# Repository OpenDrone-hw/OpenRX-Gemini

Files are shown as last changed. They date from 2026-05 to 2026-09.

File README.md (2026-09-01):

# OpenRX Gemini

Open-source dual-radio, dual-band ExpressLRS receiver for FPV aircraft. OpenRX
Gemini combines an ESP32-C3 with two LR1121 radio chains and two U.FL antenna
interfaces for Gemini and Xrossband operation.

<p>
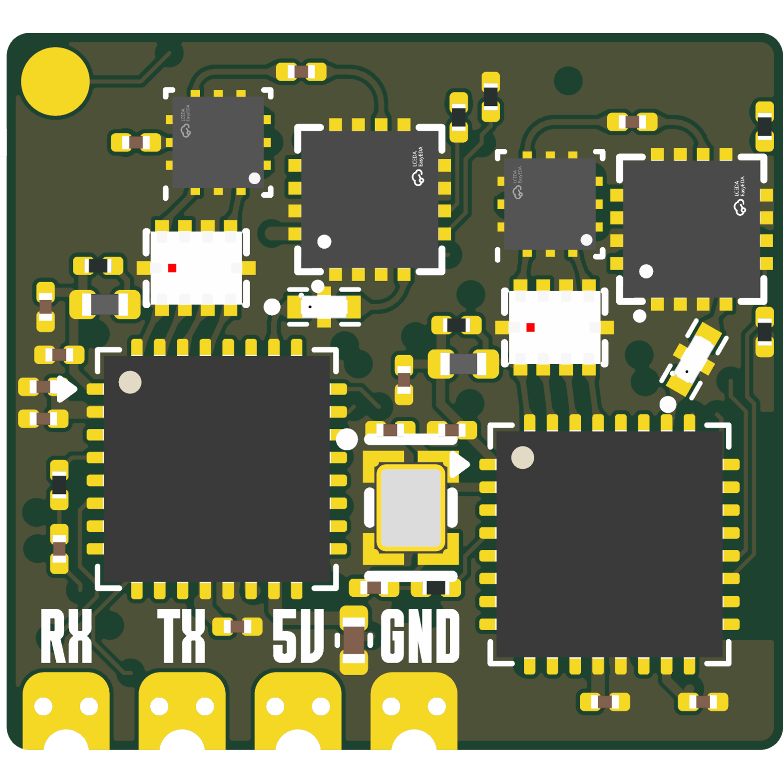
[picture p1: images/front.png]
OpenRX Gemini front

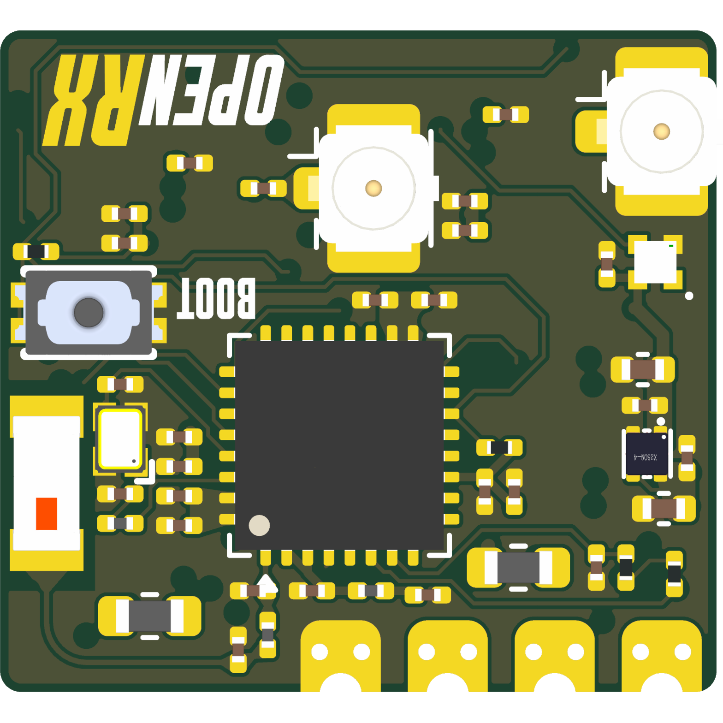
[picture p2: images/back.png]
OpenRX Gemini back

</p>







## Specifications

| | |
|---|---|
| Band | 2.4 GHz and sub-GHz, Xrossband |
| Radios | 2x LR1121 |
| Antennas | 2x U.FL |
| Telemetry power | Up to 22 dBm (158 mW) |
| Protocol | CRSF |
| MCU | ESP32-C3 |
| Input | 5 V pad |
| Firmware | ExpressLRS |
| Flashing | Betaflight passthrough or Wi-Fi |
| Dimensions | 17.0 x 15.7 mm |
| PCB | 6-layer, 1.0 mm |

Technical write-up, part list and layout constraints: [AGENTS.md](AGENTS.md).

## In the line

What pairs with what, and what is available:
[opendrone.be](https://opendrone.be).

## Contributing

See [CONTRIBUTING.md](CONTRIBUTING.md).

## License

Hardware licensed under [CERN-OHL-S-2.0](https://ohwr.org/cern_ohl_s_v2.txt),
see [LICENSE](LICENSE).

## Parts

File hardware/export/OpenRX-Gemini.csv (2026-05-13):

Reference | Qty | Value | DNP | Exclude from BOM | Exclude from Board | Footprint | Datasheet | LCSC Part | LCSC Part_1 | LCSC
AE1 | 1 | 2450AT18A100E |  |  |  | OpenRX-Shared:ANT-SMD_L3.2-W1.6 | https://lcsc.com/product-detail/RF-Antenna_JOHANSON_2450AT18A100E_2450AT18A100E_C89334.html | C89334 |  | C89334
C1,C3 | 2 | 15pF |  |  |  | Capacitor_SMD:C_0201_0603Metric |  | C85891 |  | C85891
C2,C23,C24,C39,C42,C44 | 6 | 47p |  |  |  | Capacitor_SMD:C_0201_0603Metric |  |  |  | C85908
C4,C10,C17,C25,C27,C28,C31,C41 | 8 | 1uF |  |  |  | Capacitor_SMD:C_0201_0603Metric |  | C76935 |  | C76935
C5,C6,C9,C12,C13,C14,C16,C35,C37 | 9 | 100nF |  |  |  | Capacitor_SMD:C_0201_0603Metric |  | C76939 |  | C76939
C7,C34 | 2 | 10pF |  |  |  | Capacitor_SMD:C_0201_0603Metric |  | C384956 |  | C384956
C8,C11,C18 | 3 | 10uF |  |  |  | Capacitor_SMD:C_0402_1005Metric |  | C15525 |  | C15525,C76991
C15,C36 | 2 | 47pF |  |  |  | Capacitor_SMD:C_0201_0603Metric |  | C85908 |  | C85908
C19,C33 | 2 | 2.2nF |  |  |  | Capacitor_SMD:C_0201_0603Metric |  |  |  | C161488
C20,C38 | 2 | 470nF |  |  |  | Capacitor_SMD:C_0201_0603Metric |  | C85926 |  | C85926
C21,C40 | 2 | 220pF |  |  |  | Capacitor_SMD:C_0201_0603Metric |  |  |  | C907939
C22,C43 | 2 | 1n |  |  |  | Capacitor_SMD:C_0201_0603Metric |  |  |  | C85934
C26 | 1 | 10nF |  |  |  | Capacitor_SMD:C_0201_0603Metric |  | C2168164 |  | C2168164
C29,C30 | 2 | 1.2pF |  |  |  | Capacitor_SMD:C_0201_0603Metric |  |  |  | C85895
D1 | 1 | XL-1010RGBC-WS2812B |  |  |  | OpenRX-Shared:LED-SMD_4P-L1.0-W1.0-TL_XL-1010RGBC-WS2812B |  | C5349953
FL1,FL2 | 2 | 2450FM07D0034T |  |  |  | OpenRX-Shared:FILTER-SMD_4P-L1.0-W0.5-L | https://www.lcsc.com/datasheet/C2651081.pdf | C2651081 | C2651081
J1,J2 | 2 | Conn_Coaxial_Small |  |  |  | Connector_Coaxial:U.FL_Hirose_U.FL-R-SMT-1_Vertical |  |  |  | C88374
L1,L6 | 2 | 10uH |  |  |  | Inductor_SMD:L_0603_1608Metric |  |  |  | C194437
L2 | 1 | 24nH |  |  |  | Inductor_SMD:L_0201_0603Metric |  | C206441 |  | C206441
L3 | 1 | 2.0nH |  |  |  | Inductor_SMD:L_0201_0603Metric |  |  |  | C86125
L4 | 1 | 2.5nH |  |  |  | Inductor_SMD:L_0201_0603Metric |  |  |  | C206435
L5,L7 | 2 | 47nH |  |  |  | Inductor_SMD:L_0402_1005Metric |  |  |  | C192855
OSC1 | 1 | OW7EL89CENUYO3YLC-32M |  |  |  | OpenRX-Shared:OSC-SMD_4P-L2.0-W1.6-BL_TXC_7Z |  | C22381772
R1,R10 | 2 | 200 |  |  |  | Resistor_SMD:R_0201_0603Metric |  |  |  | C274337
R2,R3,R4,R5 | 4 | 10k |  |  |  | Resistor_SMD:R_0201_0603Metric |  | C106225 |  | C106225
R6,R9 | 2 | 220 |  |  |  | Resistor_SMD:R_0201_0603Metric |  | C2074788 |  | C2074788
R7,R8,R11,R12 | 4 | 100k |  |  |  | Resistor_SMD:R_0201_0603Metric |  |  |  | C106224
T1,T2 | 2 | 0900PC16J0042001E |  |  |  | OpenRX-Shared:FILTER-SMD_10P-L2.0-W1.6-BL |  | C19842466
TP1 | 1 | RX |  |  |  | OpenRX-Shared:SolderPad_1.2x2.0mm
TP2 | 1 | TX |  |  |  | OpenRX-Shared:SolderPad_1.2x2.0mm
TP3 | 1 | 5V |  |  |  | OpenRX-Shared:SolderPad_1.2x2.0mm
TP4 | 1 | GND |  |  |  | OpenRX-Shared:SolderPad_1.2x2.0mm
U1 | 1 | ESP32-C3 |  |  |  | Package_DFN_QFN:QFN-32-1EP_5x5mm_P0.5mm_EP3.7x3.7mm | https://www.espressif.com/sites/default/files/documentation/esp32-c3_datasheet_en.pdf
U2 | 1 | TLV75533PDQNR |  |  |  | OpenRX-Shared:X2SON-4_L1.0-W1.0-P0.65-TL-EP |  | C2861882 |  | C2861882
U3,U6 | 2 | LR1121IMLTRT |  |  |  | Package_DFN_QFN:QFN-32-1EP_5x5mm_P0.5mm_EP3.7x3.7mm |  | C7498014
U4,U7 | 2 | RFX2401C |  |  |  | OpenRX-Shared:QFN-16_L3.0-W3.0-P0.50-BL-EP1.7 | https://lcsc.com/product-detail/RF-Transceiver-ICs_SKYWORKS_RFX2401C_RFX2401C_C19213.html | C19213
U5,U8 | 2 | SKY13373-460LF |  |  |  | OpenRX-Shared:QFN-12_EP_2x2_Pitch0.5mm
U9 | 1 | TS2306A 240GF MSM 9_C2976675 |  |  |  | OpenRX-Shared:SW-SMD_4P-L3.0-W2.0-P0.85-LS3.5 |  | C2976675
X1 | 1 | CJ17-400001010B20 |  |  |  | OpenRX-Shared:CRYSTAL-SMD_4P-L1.6-W1.2-BL |  | C2875272 |  | C2875272

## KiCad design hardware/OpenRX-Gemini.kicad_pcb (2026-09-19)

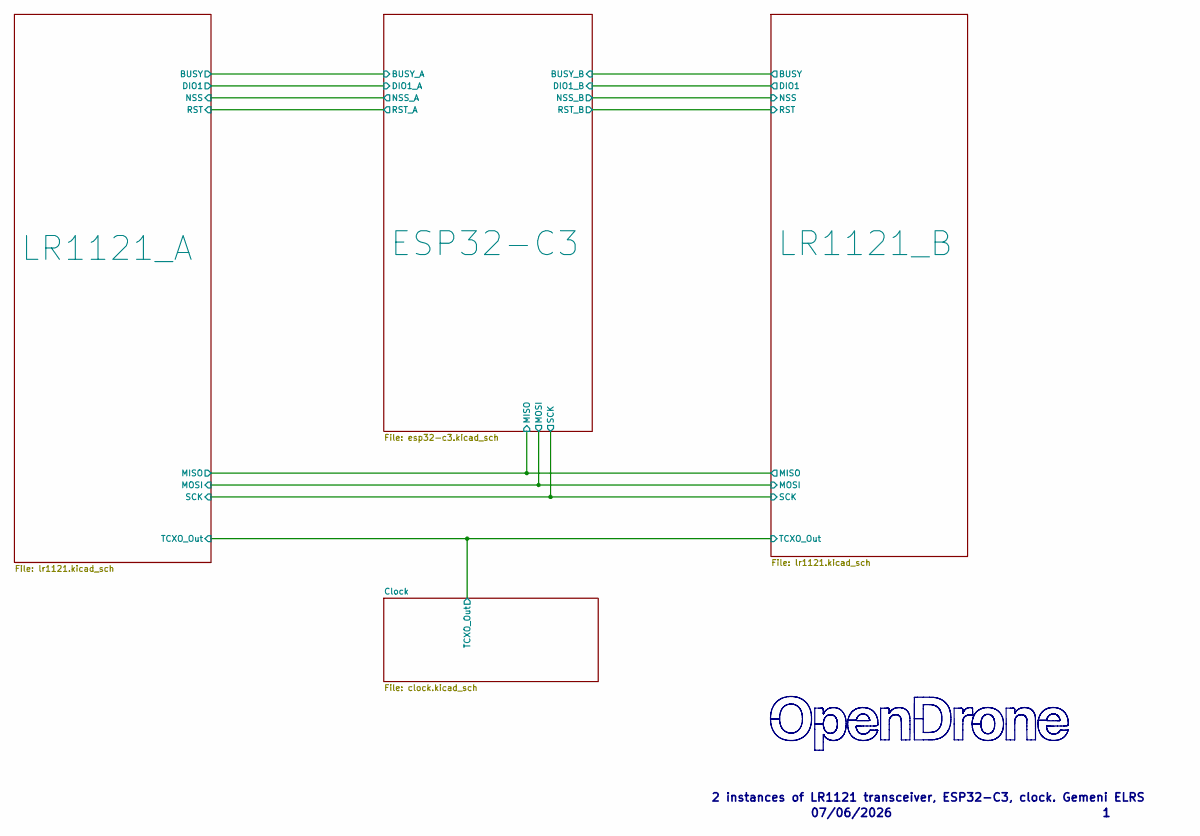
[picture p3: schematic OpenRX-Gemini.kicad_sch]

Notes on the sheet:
07/06/2026
2 instances of LR1121 transceiver, ESP32-C3, clock. Gemeni ELRS

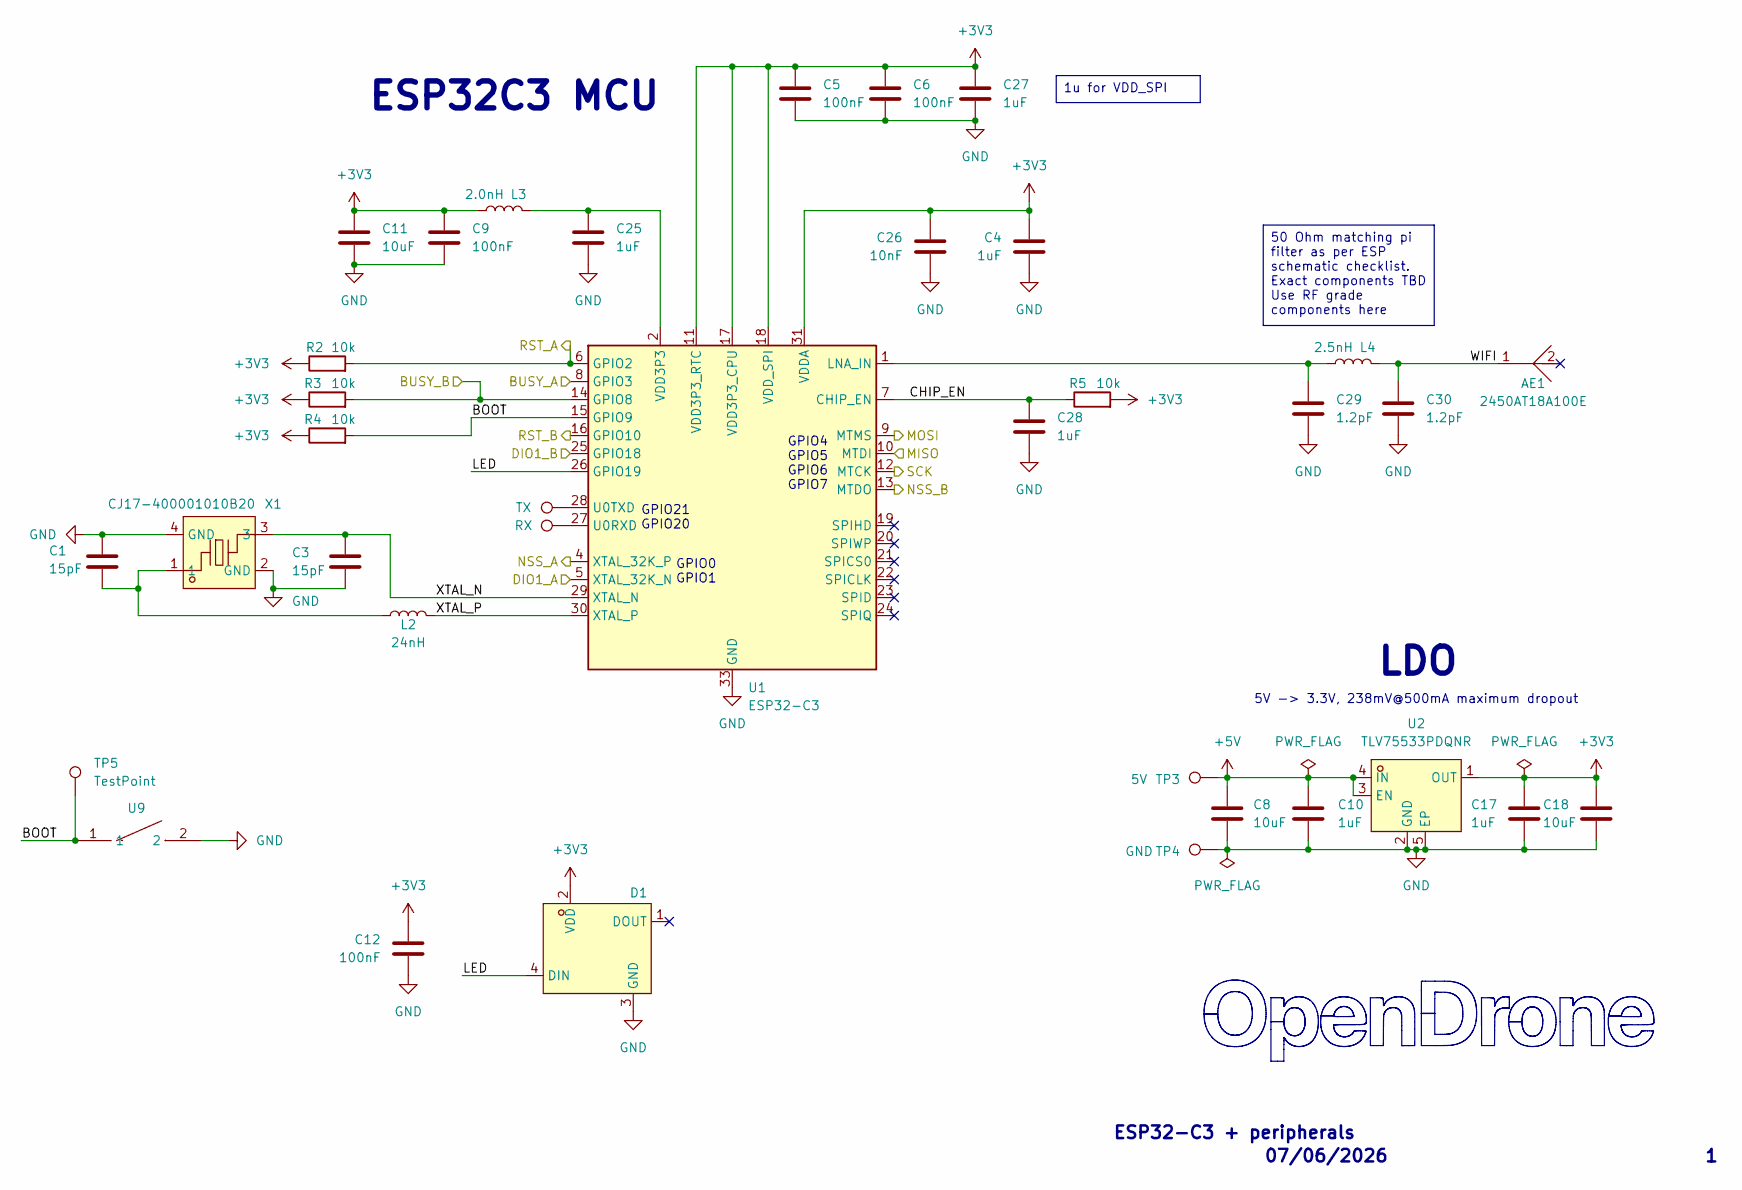
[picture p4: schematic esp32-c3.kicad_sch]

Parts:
AE1: 2450AT18A100E; ANT-SMD_L3.2-W1.6; MPN 2450AT18A100E; LCSC Part C89334
C1, C3: 15pF; C_0201_0603Metric; MPN GRM0335C1H150JA01D; LCSC C85891
C4, C10, C17, C25, C27, C28: 1uF; C_0201_0603Metric; MPN GRM033R61A105ME44D; LCSC C76935
C5, C6, C9, C12: 100nF; C_0201_0603Metric; MPN GRM033R61E104KE14D; LCSC C76939
C8, C18: 10uF; C_0402_1005Metric; MPN CL05A106MQ5NUNC; LCSC C15525
C11: 10uF; C_0402_1005Metric; MPN GRM155R60J106ME44D; LCSC C76991
C26: 10nF; C_0201_0603Metric; MPN GRM033R61A103KA01J; LCSC C2168164
C29, C30: 1.2pF; C_0201_0603Metric; MPN GRM0335C1H1R2BA01D; LCSC C85895
D1: XL-1010RGBC-WS2812B; LED-SMD_4P-L1.0-W1.0-TL_XL-1010RGBC-WS2812B; MPN XL-1010RGBC-2812B; LCSC C5349953
L2: 24nH; L_0201_0603Metric; MPN LQP03TN24NH02D; LCSC C206441
L3: 2.0nH; L_0201_0603Metric; MPN LQP03TN2N0B02D; LCSC C86125
L4: 2.5nH; L_0201_0603Metric; MPN LQP03TN2N5C02D; LCSC C206435
R2, R3, R4, R5: 10k; R_0201_0603Metric; MPN RC0201FR-0710KL; LCSC C106225
TP1: RX; SolderPad_1.2x2.0mm
TP2: TX; SolderPad_1.2x2.0mm
TP3: 5V; SolderPad_1.2x2.0mm
TP4: GND; SolderPad_1.2x2.0mm
TP5: TestPoint; TestPoint_Pad_D1.5mm
U1: ESP32-C3; QFN-32-1EP_5x5mm_P0.5mm_EP3.7x3.7mm; MPN ESP32-C3FH4; LCSC C2858491
U2: TLV75533PDQNR; X2SON-4_L1.0-W1.0-P0.65-TL-EP; MPN TLV75533PDQNR; LCSC Part C2861882
U9: TS2306A 240GF MSM 9_C2976675; SW-SMD_4P-L3.0-W2.0-P0.85-LS3.5; MPN TS2306A 240gf MSM 9; LCSC C2976675
X1: CJ17-400001010B20; CRYSTAL-SMD_4P-L1.6-W1.2-BL; MPN CJ17-400001010B20; LCSC Part C2875272

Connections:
+3V3: C4.1, C5.1, C6.1, C9.1, C11.1, C12.1, C17.1, C18.1, C26.1, C27.1, D1.2 (VDD), L3.2, R2.1, R3.1, R4.1, R5.2, U1.11 (VDD3P3_RTC), U1.17 (VDD3P3_CPU), U1.18 (VDD_SPI), U1.31 (VDDA), U1.32 (VDDA), U2.1 (OUT); also elsewhere on the board
+5V: C8.1, C10.1, TP3.1 (1_1), U2.3 (EN), U2.4 (IN)
/ESP32-C3/BOOT: R4.2, TP5.1 (1_1), U1.15 (GPIO9), U9.1
/ESP32-C3/BUSY_A: U1.8 (GPIO3); also elsewhere on the board
/ESP32-C3/BUSY_B: R3.2, U1.14 (GPIO8); also elsewhere on the board
/ESP32-C3/CHIP_EN: C28.1, R5.1, U1.7 (CHIP_EN)
/ESP32-C3/DIO1_A: U1.5 (XTAL_32K_N); also elsewhere on the board
/ESP32-C3/DIO1_B: U1.25 (GPIO18); also elsewhere on the board
/ESP32-C3/LED: D1.4 (DIN), U1.26 (GPIO19)
/ESP32-C3/MISO: U1.10 (MTDI); also elsewhere on the board
/ESP32-C3/MOSI: U1.9 (MTMS); also elsewhere on the board
/ESP32-C3/NSS_A: U1.4 (XTAL_32K_P); also elsewhere on the board
/ESP32-C3/NSS_B: U1.13 (MTDO); also elsewhere on the board
/ESP32-C3/RST_A: R2.2, U1.6 (GPIO2); also elsewhere on the board
/ESP32-C3/RST_B: U1.16 (GPIO10); also elsewhere on the board
/ESP32-C3/SCK: U1.12 (MTCK); also elsewhere on the board
/ESP32-C3/WIFI: AE1.1, C30.1, L4.1
/ESP32-C3/XTAL_N: C3.1, U1.29 (XTAL_N), X1.3
/ESP32-C3/XTAL_P: L2.2, U1.30 (XTAL_P)
GND: C1.2, C3.2, C4.2, C5.2, C6.2, C8.2, C9.2, C10.2, C11.2, C12.2, C17.2, C18.2, C25.2, C26.2, C27.2, C28.2, C29.2, C30.2, D1.3 (GND), TP4.1 (1_1), U1.33 (GND), U2.2 (GND), U2.5 (EP), U9.2, X1.2 (GND), X1.4 (GND); also elsewhere on the board
unnamed: C1.1, L2.1, X1.1
unnamed: C25.1, L3.1, U1.2 (VDD3P3), U1.3 (VDD3P3)
unnamed: C29.1, L4.2, U1.1 (LNA_IN)
unnamed: TP1.1 (1_1), U1.27 (U0RXD)
unnamed: TP2.1 (1_1), U1.28 (U0TXD)

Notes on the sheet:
ESP32C3 MCU
07/06/2026
GPIO21 GPIO20
GPIO0 GPIO1
5V -> 3.3V, 238mV@500mA maximum dropout
GPIO4 GPIO5 GPIO6 GPIO7
LDO
ESP32-C3 + peripherals
50 Ohm matching pi filter as per ESP schematic checklist. Exact components TBD Use RF grade components here
1u for VDD_SPI

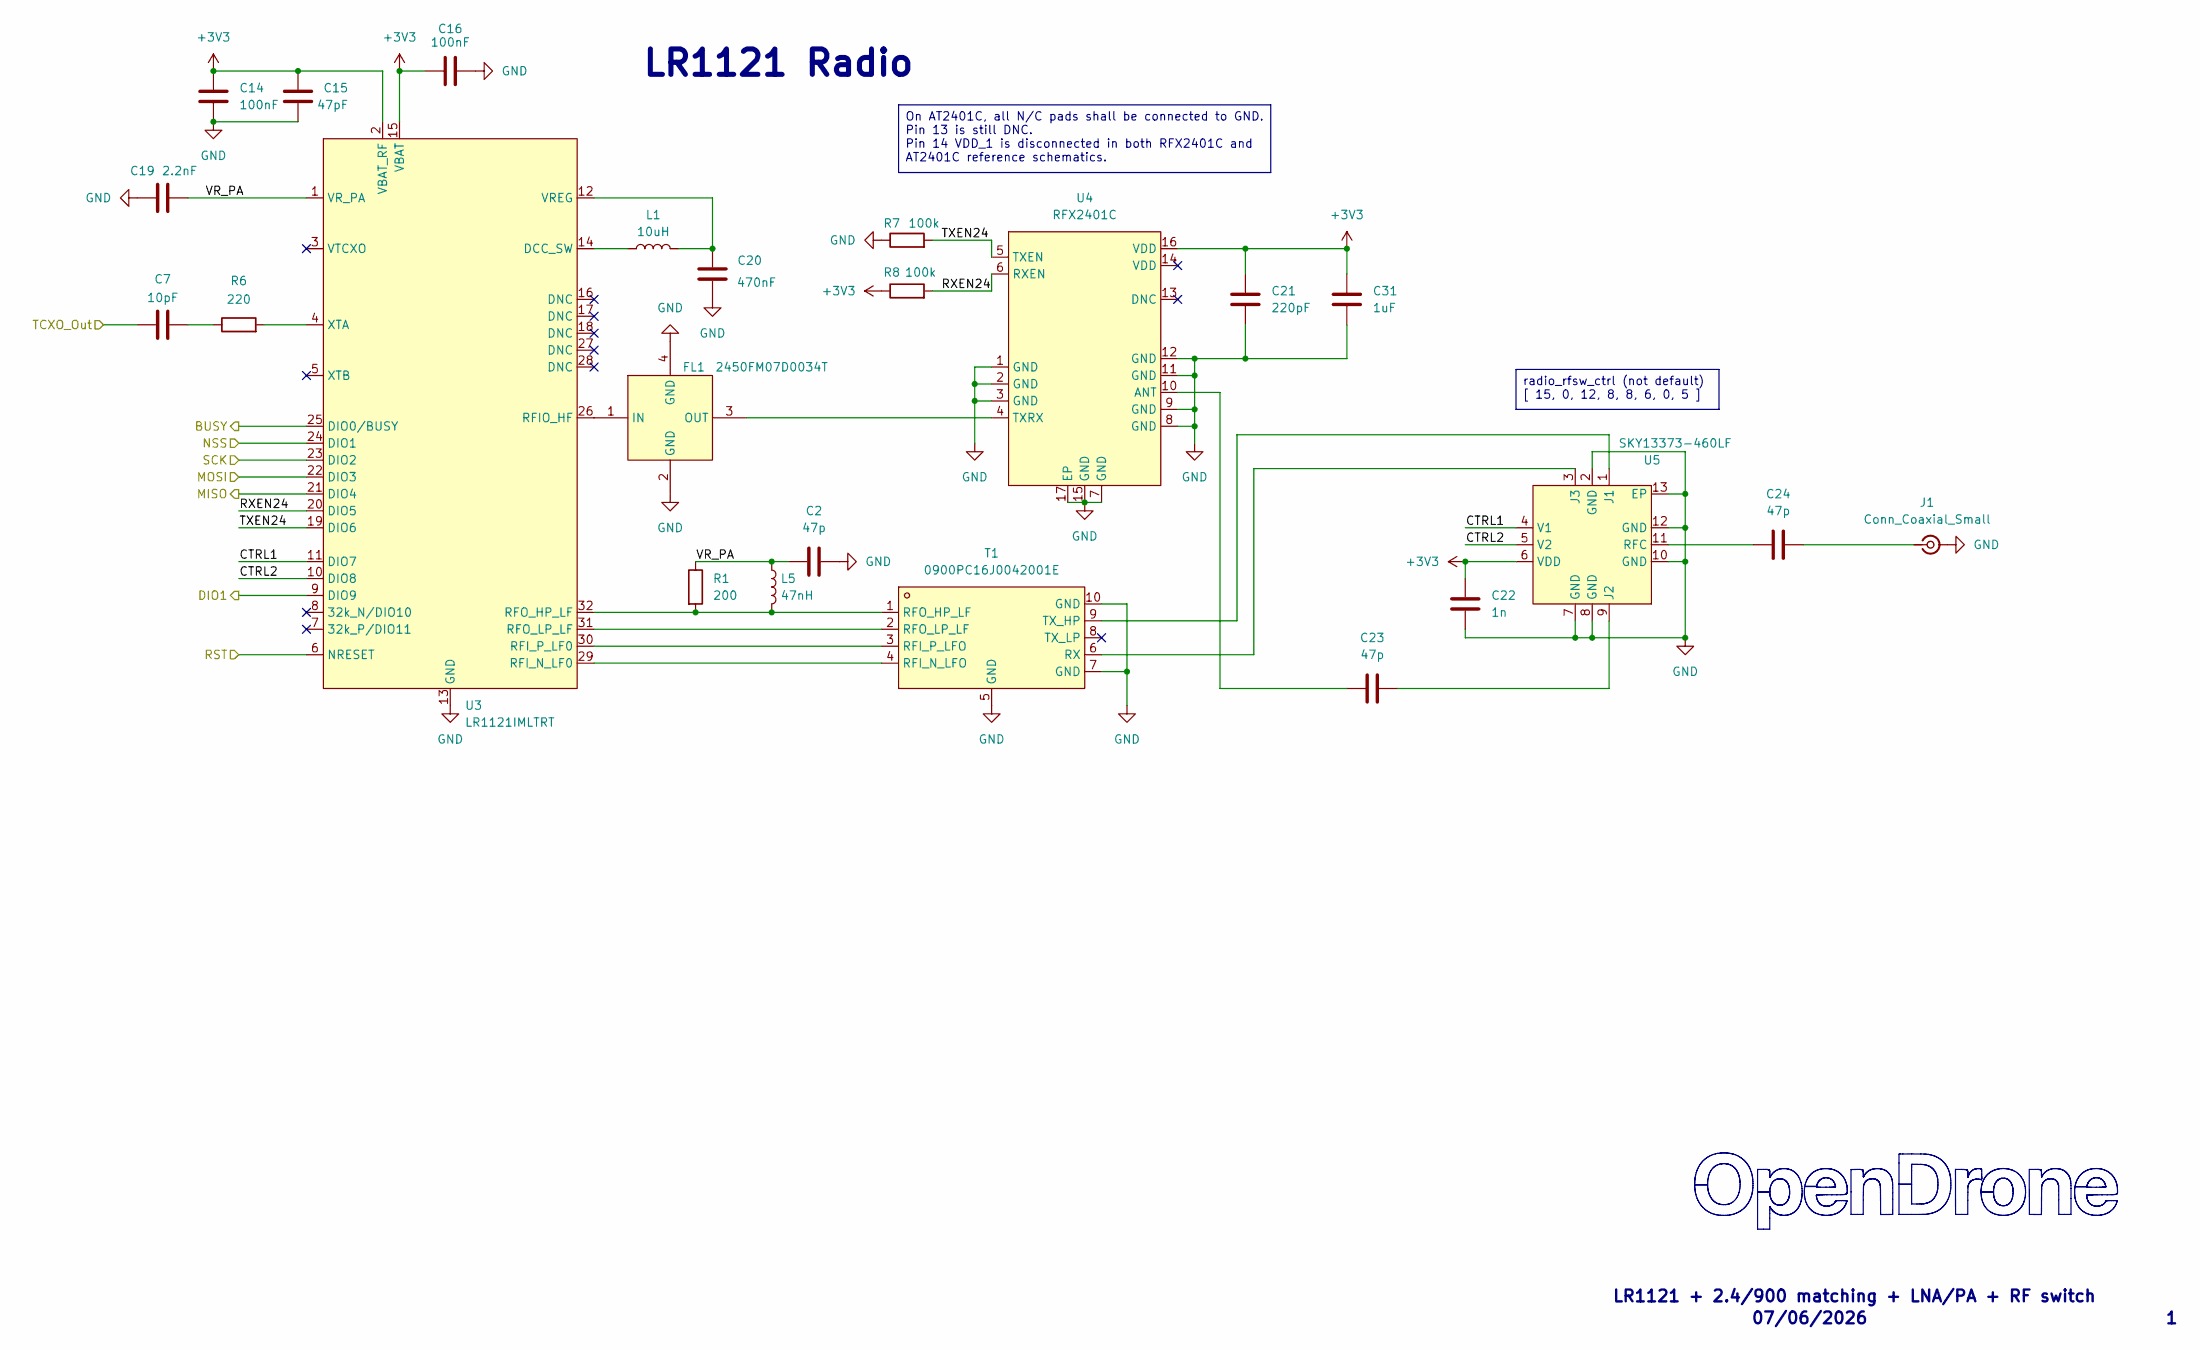
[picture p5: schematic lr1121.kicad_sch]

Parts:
C2, C23, C24: 47p; C_0201_0603Metric; MPN GRM0335C1H470JA01D; LCSC C85908
C7: 10pF; C_0201_0603Metric; MPN GRM0335C1H100FA01D; LCSC C384956
C14, C16: 100nF; C_0201_0603Metric; MPN GRM033R61E104KE14D; LCSC C76939
C15: 47pF; C_0201_0603Metric; MPN GRM0335C1H470JA01D; LCSC C85908
C19: 2.2nF; C_0201_0603Metric; MPN GRM033R71E222KA12D; LCSC C161488
C20: 470nF; C_0201_0603Metric; MPN GRM033R60J474KE90D; LCSC C85926
C21: 220pF; C_0201_0603Metric; MPN GRM0335C1E221JA01D; LCSC C907939
C22: 1n; C_0201_0603Metric; MPN GRM033R71H102KA12D; LCSC C85934
C31: 1uF; C_0201_0603Metric; MPN GRM033R61A105ME44D; LCSC C76935
FL1: 2450FM07D0034T; FILTER-SMD_4P-L1.0-W0.5-L; MPN 2450FM07D0034T; LCSC Part_1 C2651081
J1: Conn_Coaxial_Small; U.FL_Hirose_U.FL-R-SMT-1_Vertical; MPN U.FL-R-SMT-1(80); LCSC C88374
L1: 10uH; L_0603_1608Metric; MPN MLZ1608N100LT000; LCSC C194437
L5: 47nH; L_0402_1005Metric; MPN LQW15AN47NJ00D; LCSC C192855
R1: 200; R_0201_0603Metric; MPN RC0201FR-07200RL; LCSC C274337
R6: 220; R_0201_0603Metric; MPN ERJ-1GNF2200C; LCSC C2074788
R7, R8: 100k; R_0201_0603Metric; MPN RC0201FR-07100KL; LCSC C106224
T1: 0900PC16J0042001E; FILTER-SMD_10P-L2.0-W1.6-BL; MPN 0900PC16J0042001E; LCSC C19842466
U3: LR1121IMLTRT; QFN-32-1EP_5x5mm_P0.5mm_EP3.7x3.7mm; MPN LR1121IMLTRT; LCSC C7498014
U4: RFX2401C; QFN-16_L3.0-W3.0-P0.50-BL-EP1.7; MPN RFX2401C; LCSC C19213
U5: SKY13373-460LF; QFN-12_EP_2x2_Pitch0.5mm; MPN SKY13373-460LF; LCSC C150853

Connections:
+3V3: C14.1, C15.1, C16.1, C21.1, C22.1, C31.1, R8.1, U3.2 (VBAT_RF), U3.15 (VBAT), U4.16 (VDD), U5.6 (VDD); also elsewhere on the board
/Clock/TCXO_Out: C7.2; also elsewhere on the board
/ESP32-C3/BUSY_A: U3.25 (DIO0/BUSY); also elsewhere on the board
/ESP32-C3/DIO1_A: U3.9 (DIO9); also elsewhere on the board
/ESP32-C3/MISO: U3.21 (DIO4); also elsewhere on the board
/ESP32-C3/MOSI: U3.22 (DIO3); also elsewhere on the board
/ESP32-C3/NSS_A: U3.24 (DIO1); also elsewhere on the board
/ESP32-C3/RST_A: U3.6 (NRESET); also elsewhere on the board
/ESP32-C3/SCK: U3.23 (DIO2); also elsewhere on the board
/LR1121_A/CTRL1: U3.11 (DIO7), U5.4 (V1)
/LR1121_A/CTRL2: U3.10 (DIO8), U5.5 (V2)
/LR1121_A/RXEN24: R8.2, U3.20 (DIO5), U4.6 (RXEN)
/LR1121_A/TXEN24: R7.2, U3.19 (DIO6), U4.5 (TXEN)
/LR1121_A/VR_PA: C2.1, C19.1, L5.1, R1.1, U3.1 (VR_PA)
GND: C2.2, C14.2, C15.2, C16.2, C19.2, C20.1, C21.2, C22.2, C31.2, FL1.2 (GND), FL1.4 (GND), J1.2 (Ext), R7.1, T1.5 (GND), T1.7 (GND), T1.10 (GND), U3.13 (GND), U3.33 (EP), U4.1 (GND), U4.2 (GND), U4.3 (GND), U4.7 (GND), U4.8 (GND), U4.9 (GND), U4.11 (GND), U4.12 (GND), U4.15 (GND), U4.17 (EP), U5.2 (GND), U5.7 (GND), U5.8 (GND), U5.10 (GND), U5.12 (GND), U5.13 (EP); also elsewhere on the board
unnamed: C7.1, R6.1
unnamed: FL1.1 (IN), U3.26 (RFIO_HF)
unnamed: FL1.3 (OUT), U4.4 (TXRX)
unnamed: C24.2, J1.1 (In)
unnamed: T1.4 (RFI_N_LFO), U3.29 (RFI_N_LF0)
unnamed: T1.3 (RFI_P_LFO), U3.30 (RFI_P_LF0)
unnamed: L5.2, R1.2, T1.1 (RFO_HP_LF), U3.32 (RFO_HP_LF)
unnamed: T1.2 (RFO_LP_LF), U3.31 (RFO_LP_LF)
unnamed: T1.6 (RX), U5.3 (J3)
unnamed: T1.9 (TX_HP), U5.1 (J1)
unnamed: L1.1, U3.14 (DCC_SW)
unnamed: C20.2, L1.2, U3.12 (VREG)
unnamed: R6.2, U3.4 (XTA)
unnamed: C23.1, U4.10 (ANT)
unnamed: C23.2, U5.9 (J2)
unnamed: C24.1, U5.11 (RFC)

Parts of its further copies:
C33: 2.2nF; C_0201_0603Metric; MPN GRM033R71E222KA12D; LCSC C161488
C34: 10pF; C_0201_0603Metric; MPN GRM0335C1H100FA01D; LCSC C384956
C35, C37: 100nF; C_0201_0603Metric; MPN GRM033R61E104KE14D; LCSC C76939
C36: 47pF; C_0201_0603Metric; MPN GRM0335C1H470JA01D; LCSC C85908
C38: 470nF; C_0201_0603Metric; MPN GRM033R60J474KE90D; LCSC C85926
C39, C42, C44: 47p; C_0201_0603Metric; MPN GRM0335C1H470JA01D; LCSC C85908
C40: 220pF; C_0201_0603Metric; MPN GRM0335C1E221JA01D; LCSC C907939
C41: 1uF; C_0201_0603Metric; MPN GRM033R61A105ME44D; LCSC C76935
C43: 1n; C_0201_0603Metric; MPN GRM033R71H102KA12D; LCSC C85934
FL2: 2450FM07D0034T; FILTER-SMD_4P-L1.0-W0.5-L; MPN 2450FM07D0034T; LCSC Part_1 C2651081
J2: Conn_Coaxial_Small; U.FL_Hirose_U.FL-R-SMT-1_Vertical; MPN U.FL-R-SMT-1(80); LCSC C88374
L6: 10uH; L_0603_1608Metric; MPN MLZ1608N100LT000; LCSC C194437
L7: 47nH; L_0402_1005Metric; MPN LQW15AN47NJ00D; LCSC C192855
R9: 220; R_0201_0603Metric; MPN ERJ-1GNF2200C; LCSC C2074788
R10: 200; R_0201_0603Metric; MPN RC0201FR-07200RL; LCSC C274337
R11, R12: 100k; R_0201_0603Metric; MPN RC0201FR-07100KL; LCSC C106224
T2: 0900PC16J0042001E; FILTER-SMD_10P-L2.0-W1.6-BL; MPN 0900PC16J0042001E; LCSC C19842466
U6: LR1121IMLTRT; QFN-32-1EP_5x5mm_P0.5mm_EP3.7x3.7mm; MPN LR1121IMLTRT; LCSC C7498014
U7: RFX2401C; QFN-16_L3.0-W3.0-P0.50-BL-EP1.7; MPN RFX2401C; LCSC C19213
U8: SKY13373-460LF; QFN-12_EP_2x2_Pitch0.5mm; MPN SKY13373-460LF; LCSC C150853

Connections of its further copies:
+3V3: C35.1, C36.1, C37.1, C40.1, C41.1, C43.1, R12.1, U6.2 (VBAT_RF), U6.15 (VBAT), U7.16 (VDD), U8.6 (VDD); also elsewhere on the board
/Clock/TCXO_Out: C34.2; also elsewhere on the board
/ESP32-C3/BUSY_B: U6.25 (DIO0/BUSY); also elsewhere on the board
/ESP32-C3/DIO1_B: U6.9 (DIO9); also elsewhere on the board
/ESP32-C3/MISO: U6.21 (DIO4); also elsewhere on the board
/ESP32-C3/MOSI: U6.22 (DIO3); also elsewhere on the board
/ESP32-C3/NSS_B: U6.24 (DIO1); also elsewhere on the board
/ESP32-C3/RST_B: U6.6 (NRESET); also elsewhere on the board
/ESP32-C3/SCK: U6.23 (DIO2); also elsewhere on the board
/LR1121_B/CTRL1: U6.11 (DIO7), U8.4 (V1)
/LR1121_B/CTRL2: U6.10 (DIO8), U8.5 (V2)
/LR1121_B/RXEN24: R12.2, U6.20 (DIO5), U7.6 (RXEN)
/LR1121_B/TXEN24: R11.2, U6.19 (DIO6), U7.5 (TXEN)
/LR1121_B/VR_PA: C33.1, C39.1, L7.1, R10.1, U6.1 (VR_PA)
GND: C33.2, C35.2, C36.2, C37.2, C38.1, C39.2, C40.2, C41.2, C43.2, FL2.2 (GND), FL2.4 (GND), J2.2 (Ext), R11.1, T2.5 (GND), T2.7 (GND), T2.10 (GND), U6.13 (GND), U6.33 (EP), U7.1 (GND), U7.2 (GND), U7.3 (GND), U7.7 (GND), U7.8 (GND), U7.9 (GND), U7.11 (GND), U7.12 (GND), U7.15 (GND), U7.17 (EP), U8.2 (GND), U8.7 (GND), U8.8 (GND), U8.10 (GND), U8.12 (GND), U8.13 (EP); also elsewhere on the board
unnamed: C34.1, R9.1
unnamed: FL2.1 (IN), U6.26 (RFIO_HF)
unnamed: FL2.3 (OUT), U7.4 (TXRX)
unnamed: C44.2, J2.1 (In)
unnamed: T2.4 (RFI_N_LFO), U6.29 (RFI_N_LF0)
unnamed: T2.3 (RFI_P_LFO), U6.30 (RFI_P_LF0)
unnamed: L7.2, R10.2, T2.1 (RFO_HP_LF), U6.32 (RFO_HP_LF)
unnamed: T2.2 (RFO_LP_LF), U6.31 (RFO_LP_LF)
unnamed: T2.6 (RX), U8.3 (J3)
unnamed: T2.9 (TX_HP), U8.1 (J1)
unnamed: L6.1, U6.14 (DCC_SW)
unnamed: C38.2, L6.2, U6.12 (VREG)
unnamed: R9.2, U6.4 (XTA)
unnamed: C42.1, U7.10 (ANT)
unnamed: C42.2, U8.9 (J2)
unnamed: C44.1, U8.11 (RFC)

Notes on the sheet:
LR1121 + 2.4/900 matching + LNA/PA + RF switch
LR1121 Radio
07/06/2026
radio_rfsw_ctrl (not default) [ 15, 0, 12, 8, 8, 6, 0, 5 ]
On AT2401C, all N/C pads shall be connected to GND. Pin 13 is still DNC. Pin 14 VDD_1 is disconnected in both RFX2401C and AT2401C reference schematics.

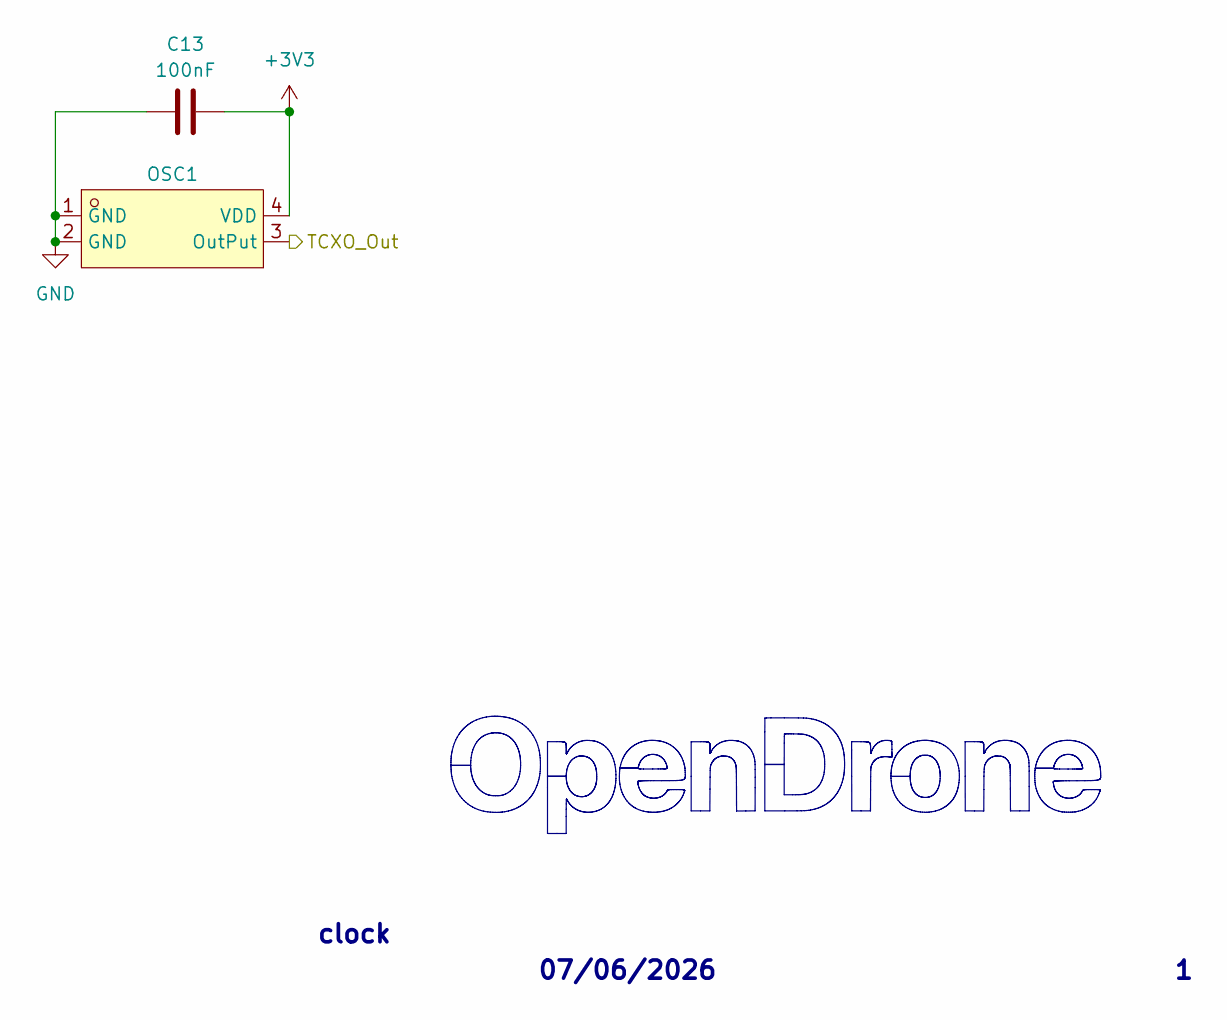
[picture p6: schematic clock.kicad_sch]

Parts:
C13: 100nF; C_0201_0603Metric; MPN GRM033R61E104KE14D; LCSC C76939
OSC1: OW7EL89CENUYO3YLC-32M; OSC-SMD_4P-L2.0-W1.6-BL_TXC_7Z; MPN OW7EL89CENUYO3YLC-32M; LCSC C22381772

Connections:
+3V3: C13.2, OSC1.4 (VDD); also elsewhere on the board
/Clock/TCXO_Out: OSC1.3 (OutPut); also elsewhere on the board
GND: C13.1, OSC1.1 (GND), OSC1.2 (GND); also elsewhere on the board

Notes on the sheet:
07/06/2026
clock

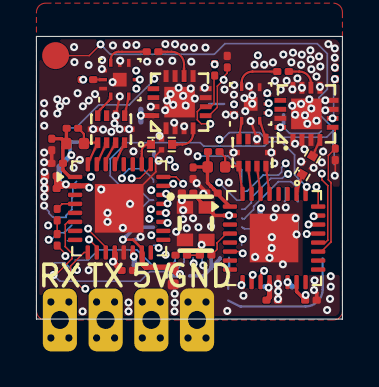
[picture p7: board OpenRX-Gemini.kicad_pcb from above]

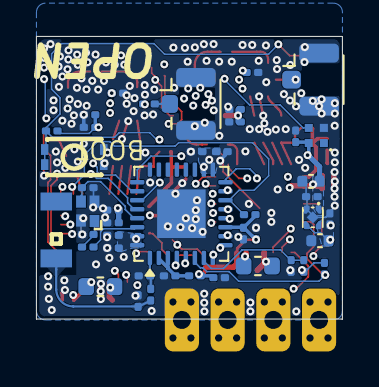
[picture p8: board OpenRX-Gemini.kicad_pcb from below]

Board: 6 copper layers, 17.0 x 15.7 mm, 86 parts (44 on the bottom side), 68 nets.

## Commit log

2026-03-23 Add OpenRX-Gemini: flagship Xrossband receiver (ESP32-C3 + 2x LR1121)
    Simultaneous 2.4GHz + 900MHz Gemini mode. Dual LR1121 on shared
    SPI bus. Tightest GPIO allocation of the family.
    Still uses SE2431L on 2.4GHz path, pending RFX2401C migration.
    [OpenRX-Gemini.kicad_pcb, OpenRX-Gemini.kicad_sch]
2026-03-23 Consolidate docs: 1 README + KICAD_WORKFLOW + 1 DESIGN.md per receiver
    - Merge SCHEMATIC.md + BOM.md into single DESIGN.md per receiver
    - Delete OPENRX_ELRS_4_RECEIVER_PORTFOLIO.md (content integrated)
    - Delete REPO_AUDIT_2026-03-23.md (issues addressed)
    - Fold CORE_BOM into README.md architecture table
    - Rename KICAD_WORKFLOW_AND_ELRS_COMPATIBILITY.md to KICAD_WORKFLOW.md
    - Rewrite KICAD_WORKFLOW with step-by-step capture instructions
    - Add shared libs and starter shared sheet from audit agent
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2026-03-23 Fix all DESIGN.md: RFX2401C, DEA LPF, LR1121 pinout, FEM control
    - Lite: remove L-match network, use DEA102700LT-6307A2 only
    - Nano: clarify DEA LPF path, mark 0.3pF as mandatory, SE2431L as EOL
    - 900: fix LR1121 RFSW description, confirm 4x4mm package
    - Dual: SE2431L→RFX2401C, FEM via LR1121 RFSW not MCU GPIO, BOM $9→$7.62
    - PWM: SE2431L→RFX2401C, DEA LPF + 0.3pF path, BOM $7.40→$6.02
    - Gemini: SE2431L→RFX2401C, fix FEM control model, BOM $10.84→$9.46
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2026-03-23 Unify library tables, import RFX2401C, Lite schematic capture
    - All 6 projects now share OpenRX-Shared + OpenRX-Lite lib tables
    - Import RFX2401C (C19213) into shared library with 3D model path fix
    - OpenRX-Lite schematic: 0 ERC errors (captured in KiCad GUI)
    - Add .gitignore for .lck and .history files
2026-03-23 OpenRX-900: add all LCSC fields, fix 4.7uF to 0402
    - C20 (4.7uF): C23733, footprint fixed from 0201 to 0402
    - R5/R6/R7 (100k): C25741, RFSW pull-downs
    - L1 (10uH): C1035, 0603 DC-DC inductor
    - U4 (LR1121): C7498014
    - U5 (32MHz TCXO): C22434888
    - T1 (Johanson IPD): C19842466
    - JP1 (UFL): C88374
    - 0 ERC errors, all components have LCSC fields
2026-03-23 OpenRX-Gemini: set up project, copy Dual schematic as base
    [OpenRX-Gemini.kicad_sch, esp32c3_lr1121_gemini.kicad_sch]
2026-03-23 Fix Gemini crystal load caps to 18pF (C62164), matching Lite and Mono
    [esp32c3_lr1121_gemini.kicad_sch]
2026-03-23 OpenRX-Gemini: dual LR1121 schematic complete, 0 ERC errors
    - Radio 1 (U4): sub-GHz via Johanson IPD → JP1 UFL
    - Radio 2 (U9): 2.4GHz via RFX2401C (U10) → DEA (USB2) → JP3 UFL
    - Shared SPI bus (SCK/MISO/MOSI), separate NSS/IRQ/BUSY/RST per radio
    - Radio 2 control: GPIO10=NSS2, GPIO9=IRQ2, GPIO1=BUSY2, GPIO0=RST2
    - FEM driven by Radio 2 RFSW (DIO5→RXEN, DIO6→TXEN)
    - Radio 1 DIO5/DIO6 have 100k pull-downs (disconnected from FEM)
    - No LED (GPIO10 used for NSS2), no boot button (GPIO9 used for IRQ2)
    - Still needs: 10k pull-up on NSS2
    [esp32c3_lr1121_gemini.kicad_sch]
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2026-03-23 Swap all solder pads to 1.2x2.0mm rounded (25%) across Lite, Mono, Gemini
    [esp32c3_lr1121_gemini.kicad_sch]
2026-03-23 Swap 32MHz TCXO to smaller 2016 package (C22381772)
    OW2EL89 (3225, 3.2x2.5mm) → OW7EL89 (2016, 2.0x1.6mm)
    Same YXC family, same pinout, same specs. Saves 1.2x0.9mm per TCXO.
    Affects Mono (1x) and Gemini (2x).
    [esp32c3_lr1121_gemini.kicad_sch]
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2026-03-23 Final topology: Mono + Gemini netlist with SKY13588 RF switch
    - SKY13588-460LF imported into shared library
    - Complete netlist for Mono (1×LR1121 + SKY13588 + Johanson IPD + DEA LPF → 1 UFL)
    - Gemini = 2× Mono RF chains + ESP32-C3 True Diversity GPIO mapping
    - GPIO maps match official ELRS Generic C3 LR1121 and True Diversity targets
    - Routing notes for RF paths included
    - Mono needs complete GPIO rewire to match ELRS target
    [OpenRX-Gemini.kicad_pcb]
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2026-03-24 Gemini: copy Mono schematic as base for dual-radio build
    [esp32c3_lr1121_gemini.kicad_sch]
2026-03-24 Gemini: copy Mono schematic + PCB as starting point
    [OpenRX-Gemini.kicad_pcb, esp32c3_lr1121_gemini.kicad_sch]
2026-03-24 Copy Gemini PCB layout to Mono
    [OpenRX-Gemini.kicad_pcb, esp32c3_lr1121_gemini.kicad_sch]
2026-03-24 Apply JLCPCB 6-layer advanced DRC rules to Mono and Gemini
    Rules applied:
    - Min clearance: 0.09mm (3.5mil)
    - Min track width: 0.09mm (3.5mil)
    - Min via diameter: 0.25mm
    - Min via drill: 0.15mm
    - Min annular ring: 0.05mm
    - Min hole-to-hole: 0.25mm
    - Default net class clearance: 0.09mm (was 0.2mm — this was the override)
    - Default track width: 0.1mm
    - Zone clearance: 0.09mm (was 0.5mm)
    [OpenRX-Gemini.kicad_pcb, esp32c3_lr1121_gemini.kicad_sch]
2026-03-24 Repo cleanup: final state for handoff
    - Clean README with architecture, BOM, CE notes, status
    - Remove dated analysis files (absorbed into FINAL_NETLIST + KICAD_WORKFLOW)
    - Remove stale OpenRX-Dual (archived), ERC reports, backups, prl files
    - Updated .gitignore for .kicad_dru, production backups
    - CERN-OHL-S v2 license confirmed
    - 3 active projects: Lite, Mono, Gemini
    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
    [OpenRX-Gemini.kicad_pcb, esp32c3_lr1121_gemini.kicad_sch]
2026-03-25 Standardize repo: .gitignore, README, license, remove production from tracking
    - Standardize .gitignore to match ecosystem template
    - Add license section to README
    - Replace LICENSE stub with full CERN-OHL-S-2.0 text
    - Remove production/ from git tracking (generated, re-exportable)
    - Remove tracked iCloud artifacts (.history 2 files)
    [OpenRX-Gemini.kicad_pcb]
2026-04-06 Update schematics: Mono RF rewiring, SKY13414 port mapping, shared libs
    Mono: disconnect IPD TX_LP (unused by ELRS), route TX_HP→RF3, RX→RF1,
    RFX2401C ANT→RF4. Matches BetaFPV SuperX topology.
    [esp32c3_lr1121_gemini.kicad_sch]
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2026-04-06 Update all DESIGN.md docs: RF paths, GPIO maps, rfsw_ctrl, known bugs
    - Mono: new SKY13414 port mapping (RF1=RX, RF3=TX_HP, RF4=2.4GHz),
    rfsw_ctrl [15,0,0,8,8,14,0,13], GPIO map, impedance notes
    - Lite/Lite-UFL: GPIO map, no-boot-button note, SPI pin difference
    - Gemini: document DIO7-2/DIO8-2 wiring bug, stale component list
    - README: current lineup table
2026-04-21 initial routing for all
    [OpenRX-Gemini.kicad_pcb, esp32c3_lr1121_gemini.kicad_sch]
2026-04-27 final route
    [OpenRX-Gemini.kicad_pcb]
2026-04-28 pre-via-normalize snapshot
    [OpenRX-Gemini.kicad_pcb]
2026-04-28 Set via netclass + dimension defaults to 0.3/0.2mm on all 4 boards
    [OpenRX-Gemini.kicad_pcb]
2026-04-28 switch to 0.2mm vias
    [OpenRX-Gemini.kicad_pcb, esp32c3_lr1121_gemini.kicad_sch]
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2026-04-28 appended other boarss
    [OpenRX-Gemini.kicad_pcb]
2026-05-08 gemini initial
    [OpenRX-Gemini.kicad_pcb, OpenRX-Gemini.kicad_sch, clock.kicad_sch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]
2026-05-13 add via testing board
    [OpenRX-Gemini-sameside.kicad_pcb, OpenRX-Gemini.kicad_pcb]
2026-05-13 fab and placement output for combined order
    [OpenRX-Gemini.csv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]
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2026-06-07 docs: reconcile README against schematics, add DESIGN_NOTES + all-variant renders
    - README rewritten against schematic/netlist ground truth (OpenFC-Lite-Mini-style
    layout, all four variants' front/back renders side-by-side).
    - Corrected antenna roles: AE1 (2450AT18A100E ceramic) is the ESP32-C3 Wi-Fi/OTA
    antenna (net WIFI) on every variant; the ELRS link antenna is FL1-OUT's load —
    47948-0001 chip antenna on Lite, U.FL on Lite-UFL/Mono/Gemini.
    - Pad pinout + per-variant pin map derived from netlists and ELRS target JSON.
    - Corrected: two distinct radio TCXOs (52 MHz SX1281 / 32 MHz LR1121); only Gemini
    has a tactile button; per-variant LED GPIO.
    - DESIGN_NOTES.md mirrors the on-can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
2026-06-10 fab/BOM/cpl as ordered
    [OpenRX-all-B_Cu.gbr, OpenRX-all-B_Mask.gbr, OpenRX-all-B_Paste.gbr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]
2026-06-10 updated HW files as ordered
    [OpenRX-all.kicad_pcb, lr1121.kicad_sch]
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2026-08-05 OpenRX-Gemini: PCB doc properties, 3D model fixes, target update, renders
    Board file gains DOC_* properties and corrected 3D model references.
    ELRS target: corrected LR1121 RF switch control table, enable radio
    DCDC. Re-rendered README images.
    [OpenRX-Gemini.kicad_pcb]
2026-08-05 docs: adopt OpenDrone repo standard
    README restructured to the standard section order; deep antenna, pad,
    pin-map, and firmware-target detail relocated to a new family DESIGN.md.
    Per-variant DESIGN.md files reconciled against the committed schematics,
    PCBs, and ELRS target JSON: SKY13373-460LF (not SKY13414), current
    radio_rfsw_ctrl values, real Gemini sheet hierarchy and refdes, Lite
    DESIGN.md no longer a copy of the Lite-UFL one. Adds CONTRIBUTING.md,
    AGENTS.md, CHANGELOG.md.
    Fact-check fixes: board sizes at Edge.Cuts centerline, KiCad 10 (not
    9/10), library claim corrected to OpenRX-Shared + Incutec submodule +
    embedded stock footprints, ELRS targets described as in-repo (not
    upstream),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
2026-08-05 changed 3.3V supply on clocks, added text, enlarged pads
    [OpenRX-Gemini.kicad_pcb, OpenRX-Gemini.kicad_sch, clock.kicad_sch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]
2026-08-06 Rewrite CONTRIBUTING for humans: file locking, render proof, sign-off
    KiCad files cannot be merged, so the doc now leads with claiming files via
    git lfs lock and issue-first discussion, the convention used by LumenPnP and
    Ultimate Hacking Keyboard. Adds .gitattributes marking design files lockable.
    Drops the internal documentation-style rule that meant nothing to contributors.
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2026-08-06 Fix contradictions and duplicated information
    Contradictions:
    - Restore shared/libs/OpenRX-Shared.kicad_sym, dropped by accident in 504d03d.
    All 7 sym-lib-tables point at it and the schematics carry 20 OpenRX-Shared:
    lib_ids, so a fresh clone could not edit or place any symbol. Restored
    byte-exact from 504d03d^.
    - README board sizes now match Edge.Cuts: Lite and Lite-UFL 10.0 x 11.5 mm,
    Mono 10.0 x 17.3 mm. Gemini was already correct at 17.0 x 15.7 mm.
    - Remove the nine dead FLASHING.md links. The file is untracked and gitignored.
    Facts that only lived behind those links are inlined: the LR1121 DIO5-DIO8 to
    RFX2401C/SKY13373 mapping, the ExpressLRS 3.5.0 minimum, and the Mono/Gem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
    [old-OpenRX-all.csv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]
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2026-08-11 update all RXs rev2 with fab files
    [OpenRX-Gemini-B_Cu.gbr, OpenRX-Gemini-B_Mask.gbr, OpenRX-Gemini-B_Paste.gbr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]
2026-08-12 Fix the RFX2401C 3D model on the Gemini variant boards
    The RFX2401C instances pointed at QFN-16_L3.0-W3.0-H0.9-P0.50.wrl with an
    offset of (-951.61, 821.31, 0), so the body rendered roughly a metre off the
    board and the land looked bare in the 3D viewer. Repointed at the RFX2401C
    model the library footprint specifies, with a zero offset, keeping the 270
    degree rotation.
    Also adds the QFN-12 model to the SKY13373 instances on these two variants,
    matching the fix already applied to Gemini and Mono.
    These boards now agree with
    OpenRX-Shared.pretty/QFN-16_L3.0-W3.0-P0.50-BL-EP1.7.kicad_mod, which always
    carried the correct model and offset. Update Footprints from Library will now
    preserve this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
    [OpenRX-Gemini-sameside.kicad_pcb, OpenRX-all.kicad_pcb]
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2026-08-12 Rev 2 board work: routing optimisations, logo placement, 3D model fixes
    Routing reworked on Lite (segments 313 to 256, vias 60 to 89), Lite-UFL
    (317 to 269, 61 to 85) and Gemini (682 to 688, 196 to 243). ExpressLRS logo
    placed on Mono.
    3D model fixes on Gemini and Mono:
    - RFX2401C (U4, U7) pointed at QFN-16_L3.0-W3.0-H0.9-P0.50.wrl with an offset
    of (-951.61, 821.31, 0), so the body rendered about a metre off the board and
    the land looked bare in the viewer. Repointed at the RFX2401C model that
    OpenRX-Shared.pretty/QFN-16_L3.0-W3.0-P0.50-BL-EP1.7.kicad_mod specifies,
    offset zeroed, 270 degree rotation kept.
    - SKY13373 (U5, U8) carried no model reference at all. Added, matching the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
    [OpenRX-Gemini.kicad_pcb]
2026-08-13 Standardise: six design docs into one AGENTS.md, trimmed README (#26)
    Adopts the org-wide shape for a multi-variant repo. The root DESIGN.md and the
    four per-variant DESIGN.md files become a single AGENTS.md: the family circuit,
    antennas, pad map, pin map and firmware targets once, then a section per
    variant. Cross-references between the old files become in-document anchors, all
    of which resolve.
    Every variant gains a .kicad_dru carrying the canonical block. Lite and
    Lite-UFL had none at all; Mono and Gemini had a single rule conditioned on a
    "50Ohm" netclass that no project in the org defines, so it could never fire.
    README drops the repository layout, build commands and per-variant detai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
2026-08-14 Normalise board setup to the line standard
    The canonical dru's copper-to-copper rule demanded 0.1 mm outer
    clearance against the 0.09 line standard stated in the same file,
    flooding DRC with false errors on standard-routed boards. Removed;
    the project-file floors gate this already. Rule floors set to the
    line standard where the routed board complies, verified by DRC:
    zero new violations.
2026-08-14 Drop the KiCad-Library submodule: nothing references it
    No symbol, footprint or 3D model in the design resolves through
    libs/KiCad-Library; every part is in the repo's local libraries. The
    submodule only cost --recursive clones and pin maintenance. Lib-table
    rows for the dead Incutec nickname removed so KiCad stops warning.
2026-08-14 Rev 3.1 working state: zone refills, fab option names, ordered sets
    Mono and Gemini PCB zone refills and priority renumbering, Lite-UFL J1
    LCSC field, fabrication-toolkit archive names per revision, the dated
    2026-08-06 production sets for Lite-UFL and Mono as the record of what
    was ordered, competitor RX catalogue, stale export STEPs deleted. The
    repo-specific .gitignore tail restores flashing/bringup notes and the
    firmware handoff bundle to local-only, plus regenerable dumps.
    [OpenRX-Gemini.kicad_pcb, OpenRX-all.kicad_pcb]
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2026-08-14 Rebuild E6 substitute STEP models from the trusted wrl geometry
    The .step files beside these .wrl models were different parts (USB-C
    3.5x oversized, etc), and the upstream LCSC .step is the same wrong
    file, so kicad-cli --subst-models shipped wrong geometry in every STEP
    export while the 3D viewer looked perfect. Rebuilt as tessellated STEP
    solids from the .wrl the viewer renders, via
    OpenDrone-Scripts/kicad/wrl_to_step.py: bbox and origin now match to
    0.000 mm. check_models reports zero E6, export unblocked.
    [OpenRX-Gemini.kicad_pcb]
2026-08-14 Fix the Gemini archive name typo: Gemeni -> Gemini_rev2
    Matches the Lite_rev2 / Mono_rev2 naming. Set re-exported headless,
    byte-identical BOM and positions to the misnamed set.
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2026-08-15 docs: standardise AGENTS.md, complete spec table, fix flash targets
    AGENTS.md rebuilt on the org template and fact-checked against the design files. README spec table completed (telemetry power, dimensions, 1.0 mm PCB for all variants) and maintainer added. FLASHING.md build targets corrected to opendrone.rx_2400.lite / .lite_ufl. DOC text variables cleaned of em dashes.
2026-08-22 3D models: retarget to KiCad stock, fix placement
    Replaces easyeda2kicad 3D models with KiCad's own where a dimension-matched
    equivalent exists. The easyeda models run 20-100x denser for the same package
    and most carry the LCEDA watermark modelled as raised geometry, which renders
    on every CAD picture of the board and is not on the real part.
    Only the (model ...) reference, offset and rotation are touched. No footprint,
    pad, land pattern, net, placement or value is modified. Applied to the footprint
    LIBRARY and the boards together: fixing only the .pretty is invisible because
    each board carries its own footprint copy, and fixing only the .kicad_pcb is
    surface level because the next placemen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
    [OpenRX-Gemini.kicad_pcb, OpenRX-all.kicad_pcb]
2026-08-25 sch: standardise LCSC/Manufacturer/MPN fields across all variants
    Migrated LCSC part numbers out of variant-specific LCSC_Part fields into
    the standard LCSC field, and backfilled Manufacturer/MPN from the LCSC
    catalogue, on all four board variants (Gemini, Lite, Lite-UFL, Mono) and
    the shared ESP32-C3/SX1281 RX core sheet.
    kicad-skip reflowed each file on save, so the diffs are large but purely
    formatting; a structural S-expression diff and ERC re-run on all 12
    affected schematics (including the 4 unmodified top-level sheets) confirm
    only property values changed, no nets/placement/footprints touched.
    Known gap: L2/L3 in OpenRX-Gemini/esp32c3_lr1121_gemini.kicad_sch carry
    LCSC C1035, which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
    [clock.kicad_sch, esp32-c3.kicad_sch, esp32c3_lr1121_gemini.kicad_sch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]
2026-08-31 AGENTS.md: sync from the bench mirror rework (#45)
    Formatting repairs plus verified corrections from the 2026-08-31 bench
    session (fact-checked against datasheets, board READMEs and firmware
    sources). Details per file in OpenDrone-Testing commit 06034b3.
2026-09-01 chore: standardize OpenRX design assets
    [OpenRX-Gemini.kicad_pcb, OpenRX-all.kicad_pcb]
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2026-09-01 Split board into its own hardware repository
    [OpenRX-Gemini-B_Cu.gbr, OpenRX-Gemini-B_Mask.gbr, OpenRX-Gemini-B_Paste.gbr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]
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2026-09-09 Refill zones and point the board at the project library
    Regenerates the teardrop zones after the fill pass, adds the
    OPENDRONE_LIB project-library property, and removes em dashes from the
    DOC_RATING and DOC_TAGLINE strings.
    Claude-Session: https://claude.ai/code/session_01HXA6SP2VEuBZn7yMrez3es
    [OpenRX-Gemini.kicad_pcb]
2026-09-09 Give every placed part an LCSC field
    The BOM exporter reads a field named LCSC. Parts that carried only
    "LCSC Part" were dropped from the supplier BOM and the pick and place
    without a warning, and ESP32-C3, the 15uH DC-DC inductor and
    SKY13373-460LF carried no LCSC anywhere.
    Adds LCSC to the schematic symbols and mirrors it onto the board
    footprints, which is the only route for references created by a
    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
    [OpenRX-Gemini.kicad_pcb, esp32-c3.kicad_sch, lr1121.kicad_sch]
2026-09-09 Set the titleblock revision to rev2
    quote_pack.py syncs the titleblock from the release stem; recording it
    keeps the design source stable across exports.
    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
    [OpenRX-Gemini.kicad_pcb]
2026-11-11 docs(rules): kicad-skip cannot round-trip KiCad 10 schematics (#11)
    Syncs the shared Rules section from OpenDrone-hw/hardware-template (PR 16).
2026-11-14 README: describe OpenRX as a general-purpose radio control receiver module (#12)
    Requested by Stan, 14 Nov 2026: "fix the public readme's".
    - Opening lines: ExpressLRS radio control receiver module with telemetry, for cars, boats, robots and aircraft; technical facts unchanged.
    - Connection: serial (CRSF) on the RX/TX pads to a controller; a flight controller is named as one example.
    - PWM output is not claimed: the shipped ExpressLRS layout for this board defines no `pwm_outputs`, so the web UI offers no PWM channels.
    README text only; no KiCad files touched.
    Founder-session: 2026-11-14: Stan, 14 Nov 2026: "fix the public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
